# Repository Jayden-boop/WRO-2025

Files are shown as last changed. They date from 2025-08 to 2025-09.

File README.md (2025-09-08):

## Content

* `t-photos` contains 2 photos of the team as well as a personal photo of each member.
* `v-photos` contains 6 photos of the vehicle (from every side, from top and bottom)
* `video` contains the video.md file with the link to a video where a driving demonstration exists
* `schemes` contains one or several schematic diagrams in the form of JPEG, PNG, or PDF of the electromechanical components illustrating all the elements (electronic components and motors) used in the vehicle and how they connect to each other.
* `src` contains the code of control software for all components that were programmed to participate in the competition
* `models` is for the files for models used by 3D printers, laser cutting machines, and CNC machines to produce the vehicle elements. If there is nothing to add to this location, the directory can be removed.
* `other` is for other files, which can be used to understand how to prepare the vehicle for the competition. It may include documentation on how to connect to an SBC/SBM and upload files there, datasets, hardware specifications, communication protocols descriptions etc. If there is nothing to add to this location, the directory can be removed.

Table of Contents
=====

- [The Team](#the-team)
  
  - [Team Photos](#team-photo)
  - [Jayden](#jayden)
  - [Arham](#arham)
  - [Trevor](#trevor)

- [JAT | WRO Documentation](#jat-wro-documentation)
  
  - [Task](#task)
  - [Challenge Descriptions](#challenge-descriptions)
    - [1. Open Challenge](#1-open-challenge)
    - [2. Obstacle Challenge](#2-obstacle-challenge)

- [Our Robot](#our-robot)
  
  - [Video Demonstrations](#video-demonstrations)

- [Engineering Design & Strategy](#engineering-design--strategy)
  
  - [Mobility Management](#mobility-management)
    - [Motor Selection and Implementation](#motor-selection-and-implementation)
    - [Wheels and Drivetrain Rationale](#wheels-and-drivetrain-rationale)
  - [Power and Sense Management](#power-and-sense-management)
    - [Power Source and Distribution](#power-source-and-distribution)
    - [Wiring Diagram](#wiring-diagram)
    - [Sensor Selection and Rationale](#sensor-selection-and-rationale)

  - [Custom Chassis Parts](#custom-chassis-parts)
  - [Mechanical Components](#mechanical-components)

- [Cost Report](#cost-report)

- [Measurements](#measurements)

- [Assembly Guide](#assembly-guide)
  
  - [Overview](#overview)
  - [Required Tools](#required-tools)
  - [Required Components](#required-components)
  - [Assembly Steps](#assembly-steps)
    - [Step 1: Chassis Foundation Assembly](#step-1-chassis-foundation-assembly)
    - [Step 2: Platform and Electronics Mounting](#step-2-platform-and-electronics-mounting)
    - [Step 3: Sensor Integration](#step-3-sensor-integration)
    - [Step 4: Drive System Integration](#step-4-drive-system-integration)
    - [Step 5: Custom Steering System Assembly](#step-5-custom-steering-system-assembly)
    - [Step 6: Wheel and Tire Installation](#step-6-wheel-and-tire-installation)
    - [Step 7: System Wiring and Connections](#step-7-system-wiring-and-connections)
    - [Step 8: Final Assembly and Testing](#step-8-final-assembly-and-testing)

- [Obstacle Avoidance](#obstacle-avoidance)
  
  - [1. Pillar Detection](#1-pillar-detection)
  - [2. Pillar Filtering and Prioritization](#2-pillar-filtering-and-prioritization)
  - [3. Steering and Control](#3-steering-and-control)
  - [4. Emergency Collision Handling](#4-emergency-collision-handling)
  - [5. Edge Case Handling](#5-edge-case-handling)
  - [6. Turn Handling, Line Detection, and Lap Counting](#6-turn-handling-line-detection-and-lap-counting)
  - [7. Exiting the Parking Lot](#7-exiting-the-parking-lot)
  - [8. Parking Sequence](#8-parking-sequence)

# The Team

## Team Photo

<table align="center">
  <tr>
    <td align="center" style="border: 2px solid #ccc; padding: 10px;">
      Normal Team Photo<br>
      <strong><em>Left: Jayden, Middle: Arham, Right: Trevor</em></strong>
    </td>
  </tr>
</table>

---

### Jayden

<p align="center">
  
</p>

> **Jayden Li** is a Grade 11 Student at Anderson CVI who loves programming, math, and robotics. In his free time, he plays and watches basketball. 

---

### Arham

<p align="center">
  
</p>

> **Syed Arham Wasti** is a Grade 11 Student at Anderson CVI who takes an interest in computer science and machine learning. His ambition drives him to use his skills to address issues he deeply cares about.

---

### Trevor

<p align="center">
  
</p>

> **Trevor Mcaskin** is a Grade 11 Student at Anderson who loves problem-solving. He enjoys working hands-on with robotics and mechanical systems. One of his hobbies is playing video games.

# JAT WRO Documentation

## Task

The WRO 2025 Future Engineers Self-Driving Cars Challenge tasks teams with designing an autonomous vehicle to complete dynamic racetrack laps and perform parallel parking, adapting to randomized layouts and traffic signs. Teams must also document their engineering process in a public GitHub repository, showcasing innovation, adaptability, and technical problem-solving.

### Challenge Descriptions:

#### 1\. Open Challenge

In this challenge, the vehicle must autonomously complete three laps on a racetrack whose layout randomizes each round. The run must be completed within the 3-minute time limit; otherwise, the attempt is terminated.

**Key Elements:**

-  The track may feature randomized corridor widths (narrow or wide sections) and varying starting positions.

- The track configuration (e.g., wall placements, starting zones) is determined by a randomization process before each round.

-  The navigation algorithms of the vehicle are critical, having to adapt in real time to an unseen wall and course arrangement without human intervention.

**Performance Goal:**
The goal is to maximize the consistency and speed of laps under unknown track conditions.

#### 2\. Obstacle Challenge

In this challenge, the vehicle must complete three complete laps on a track with randomly placed traffic signs and then perform a parallel parking maneuver in a designated area. If the vehicle collides with a traffic sign and knocks it out of the designated zone, the run is considered unsuccessful.

**Key Elements:**

- Red and green pillars indicate required driving lanes (red = keep right, green = keep left). The vehicle must obey these rules without displacing the signs.
- After completing laps, the vehicle must park within a narrow, variable-sized parking space. Starting inside the parking lot and achieving parallel alignment earns bonus points.

**Randomization factors:**

- Traffic sign positions
- Parking lot placement
- Driving direction (clockwise/counterclockwise)

**Performance Goal:**
Complete the 3 laps without faults and complete a precise parallel parking maneuver whilst adapting to randomized factors.

# 

Our Robot
=====

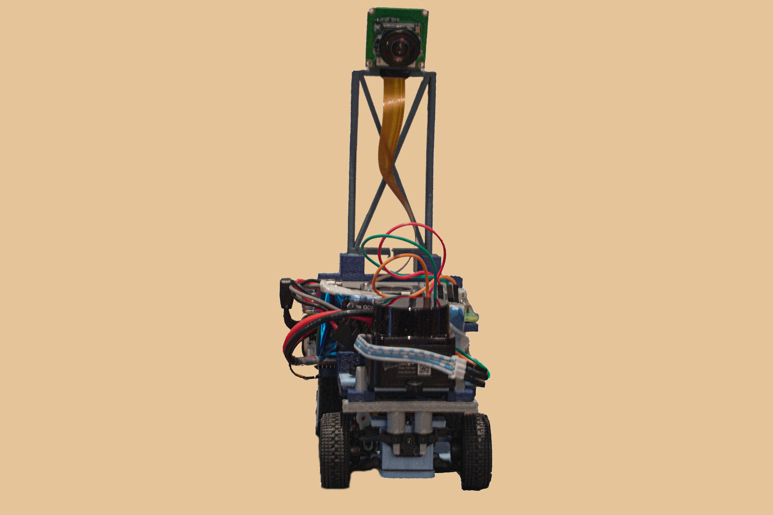
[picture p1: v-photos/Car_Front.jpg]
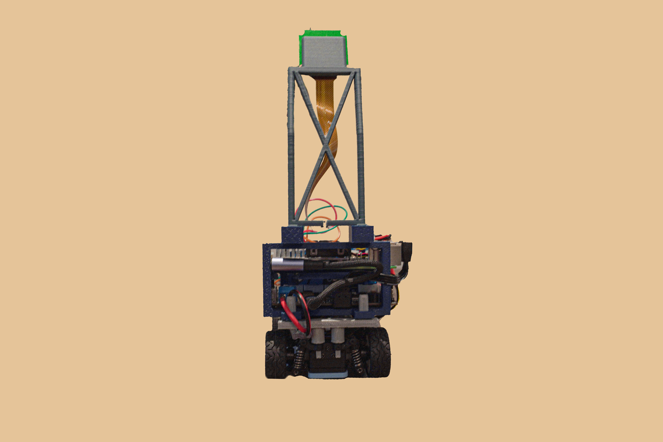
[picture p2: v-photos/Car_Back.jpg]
|  |  |
|:---:|:---:|
| *Front* | *Back* |
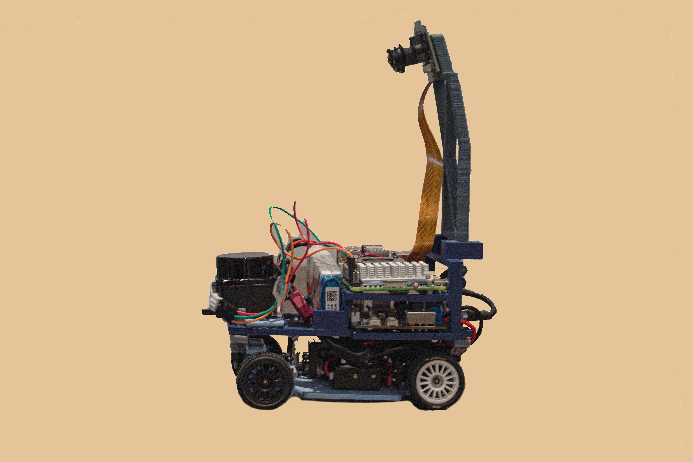
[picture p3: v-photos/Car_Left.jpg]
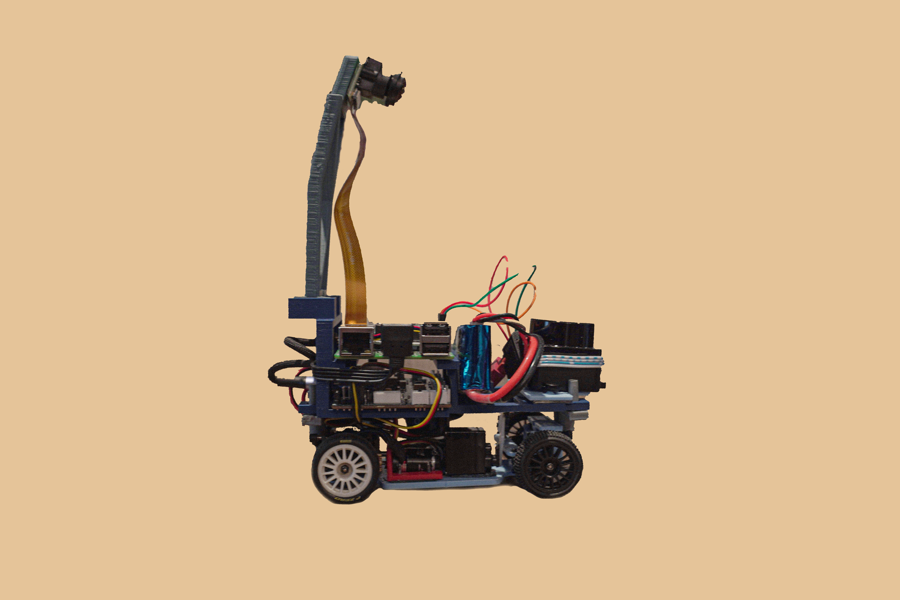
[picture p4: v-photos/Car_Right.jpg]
|   |   |
| *Left* | *Right* |
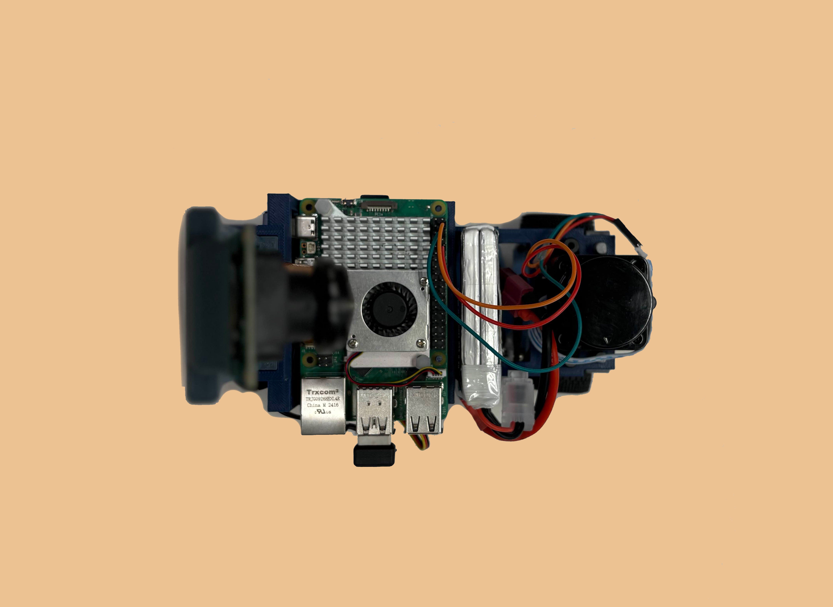
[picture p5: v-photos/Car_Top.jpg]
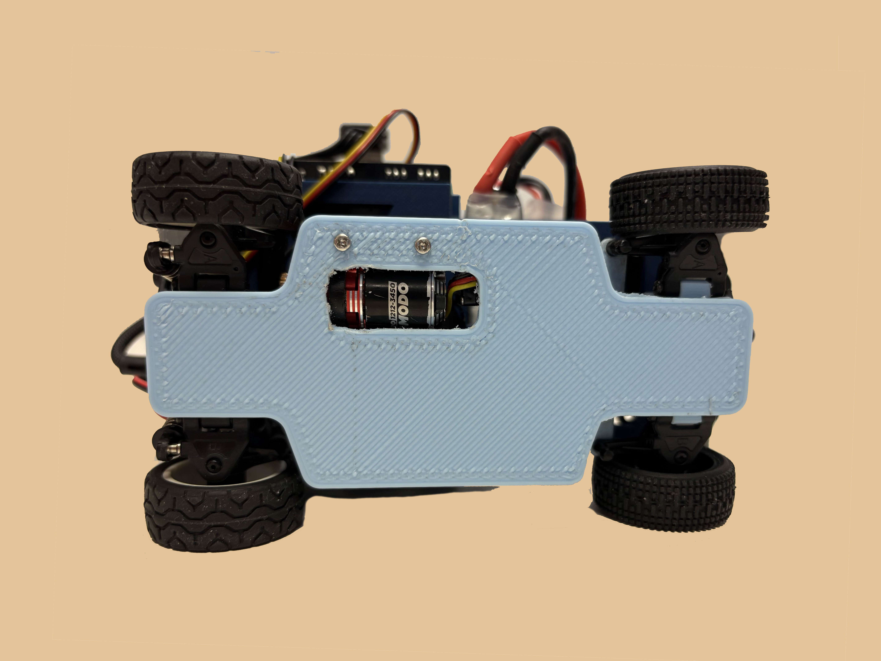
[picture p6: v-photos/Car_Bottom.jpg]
|  |  |
| *Top* | *Bottom* |

<p align="center">
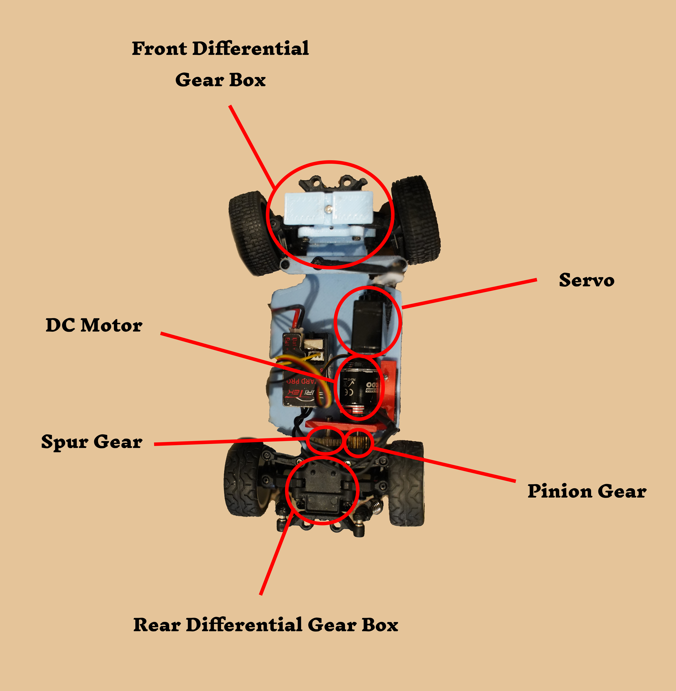
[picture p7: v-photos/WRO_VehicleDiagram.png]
 
   </p>
<br>

<br>

## Video Demonstrations

<table>
  <tr>
    <th>Open Challenge</th>
    <th>Obstacle Challenge</th>
  </tr>
  <tr>
    <td align="center">
      <a href="https://www.youtube.com/watch?v=GPGMuM1HHgo" target="_blank">
        Open Challenge
      </a>
    </td>
    <td align="center">
      <a href="https://www.youtube.com/watch?v=hhrCKOZkAMQ" target="_blank">
        Obstacle Challenge
      </a>
    </td>
  </tr>
</table>

<div align="center"><small><em>Click the images for the video demonstrations!</em></small></div>

# Engineering Design & Strategy

This section outlines the core engineering principles and strategic decisions that guided the development of our autonomous vehicle. We have broken down our design process into the key categories evaluated in the competition: Mobility, Power & Sensing, and Obstacle Management.

## Mobility Management

Effective mobility is central to navigating the course quickly and accurately. Our design focuses on a responsive drivetrain with precise steering control.

### Motor Selection and Implementation

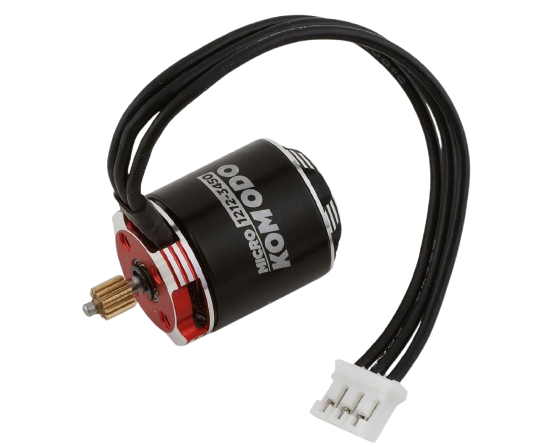
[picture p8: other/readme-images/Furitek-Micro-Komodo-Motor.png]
Furitek Micro Komodo Motor
<table width="800px"> <tr> <td width="400px" style="text-align: left; vertical-align: top;">  </td> <td width="400px" style="text-align: left; vertical-align: top;"> <h3>Furitek Micro Komodo Motor</h3> <ul> <li><b>KV:</b> 3450 RPM/Volt</li> <li><b>Power:</b> 120W</li> <li><b>Battery:</b> 2–3S LiPo</li> <li><b>Type:</b> Brushless</li> <li><b>Weight:</b> 17.5 g</li> </ul> </td> </tr> </table>

The Furitek Micro Komodo was selected for its exceptional power-to-weight ratio and precise speed control. As a brushless motor, it offers higher efficiency, a longer lifespan, and superior performance compared to brushed alternatives. Its ability to operate smoothly at both high and very low speeds is a significant advantage, providing the raw acceleration needed for fast laps and the delicate, slow-speed control required for the parallel parking maneuver. 

A 3D motor mount secures the motor to the chassis, allowing for full transfer of energy to the rear gearbox. It is screwed into the motor and chassis using M3 screws. 

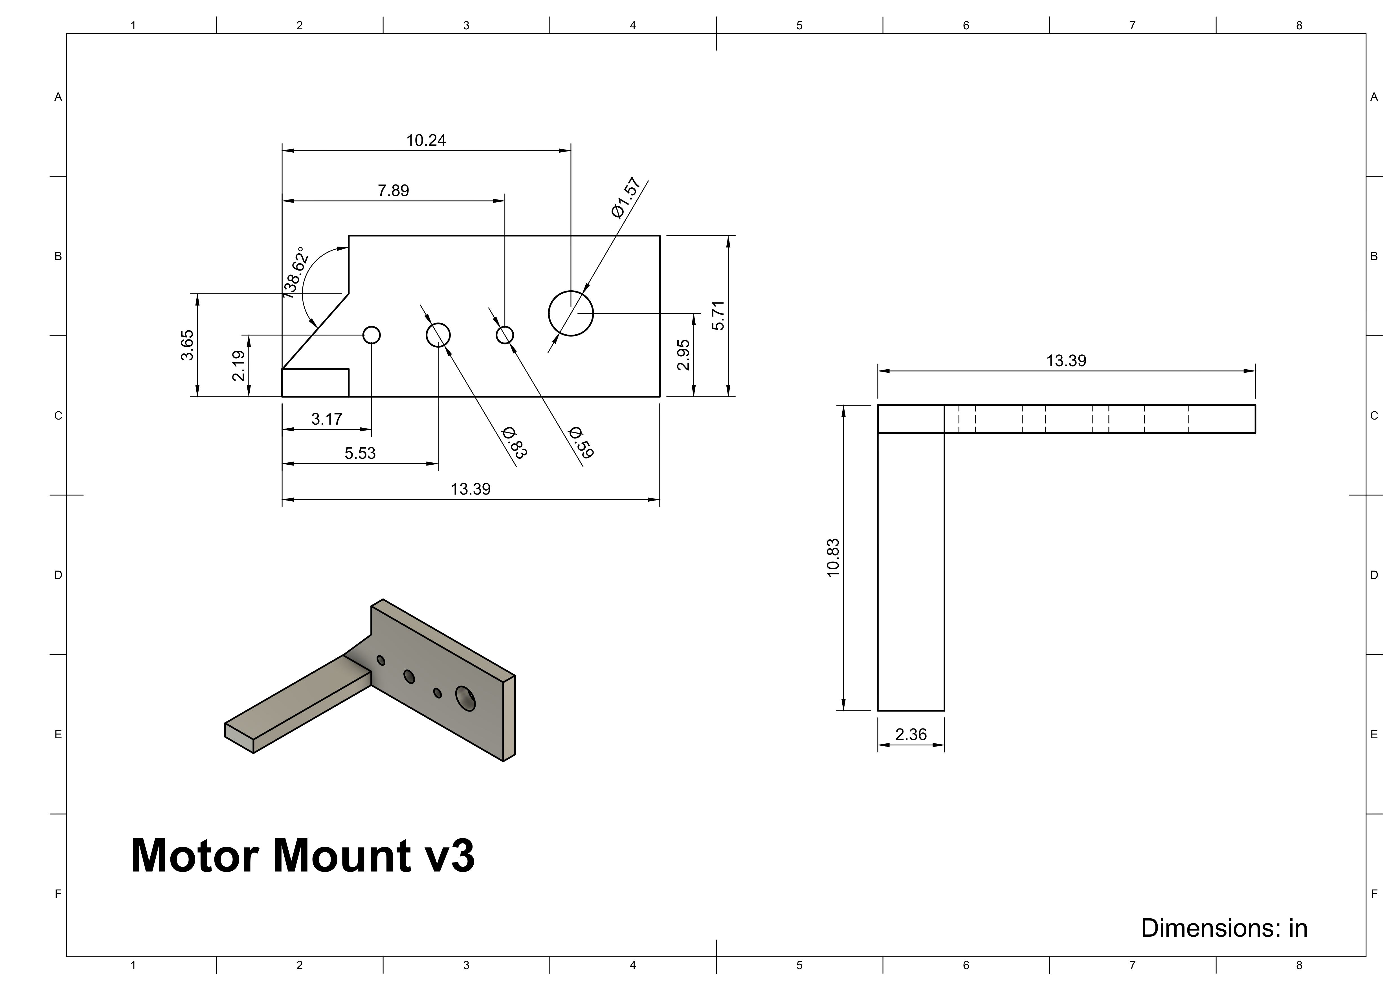
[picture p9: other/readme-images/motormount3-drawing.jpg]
Motor Mount Drawing


<table width="800px">
  <tr>
    <td width="400px" style="text-align: left; vertical-align: top;">
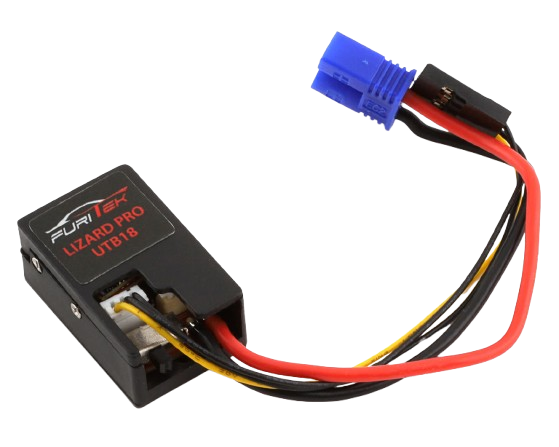
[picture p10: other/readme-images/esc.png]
Furitek Lizard Pro ESC
      
    </td>
    <td width="400px" style="text-align: left; vertical-align: top;">
      <h3>Furitek Lizard Pro ESC</h3>
      <ul>
        <li><b>Current:</b> 30A Constant / 50A Burst</li>
        <li><b>Battery:</b> 2–3S LiPo</li>
        <li><b>BEC:</b> 5V or 6.5V @ 2.5A</li>
        <li><b>Type:</b> Brushed/Brushless</li>
        <li><b>Weight:</b> 3.7 g</li>
      </ul>
    </td>
  </tr>
</table>

The ESC was selected for its light weight and small frame. It allows for simple calibration using the FURITEK app and supports the BLDC motor we selected. 

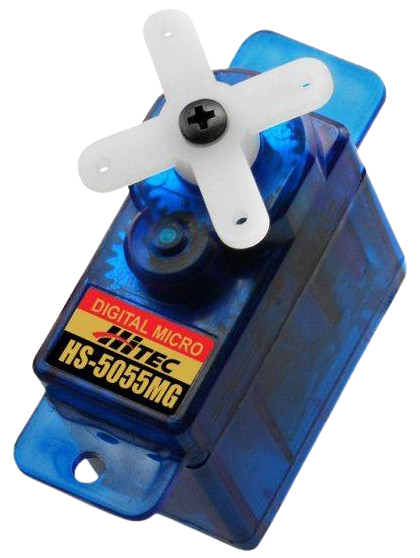
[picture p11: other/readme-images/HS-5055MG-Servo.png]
HS-5055MG Servo
<table width="800px"> <tr> <td width="400px" style="text-align: left; vertical-align: top;">  </td> <td width="400px" style="text-align: left; vertical-align: top; padding: 0;"> <h3>HS-5055MG Servo</h3> <ul> <li><b>Torque (6.0V):</b> 1.4 kg/cm</li> <li><b>Speed (6.0V):</b> 0.14 sec/60°</li> <li><b>Gears:</b> Metal</li> <li><b>Type:</b> Digital</li> <li><b>Weight:</b> 9.5 g</li> </ul> </td> </tr> </table>

Accurate path following is managed by a PID controller, which requires a steering servo capable of making small, precise, and rapid adjustments. The HS-5055MG was chosen for its digital precision and metal gear construction, providing the durability and responsiveness needed to translate the PID controller's outputs into exact steering angles. This ensures the vehicle can hold its line with minimal error.

### Wheels and Drivetrain Rationale

We use GT24 Carisma Wheels and Tires for their traction characteristics, ensuring consistent grip and power delivery. Other 1/24 scale RC car wheels and tires can be substituted.

## Power and Sense Management

A reliable power system and an accurate sensor suite are the foundation of any autonomous system. Our strategy was to choose components that provide clean power and rich, low-latency data to our control system.

### Power Source and Distribution

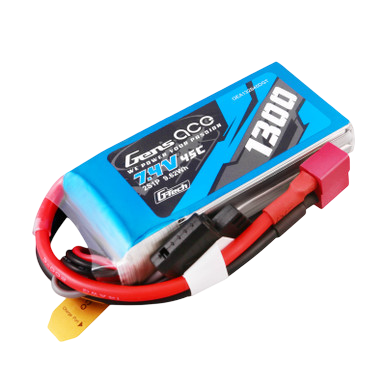
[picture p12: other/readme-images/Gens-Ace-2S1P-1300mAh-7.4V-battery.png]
Gens Ace 2S1P 1300mAh 7.4V battery
<table width="800px"> <tr> <td width="400px" style="text-align: left; vertical-align: top;">  </td> <td width="400px" style="text-align: left; vertical-align: top;"> <h3>Gens Ace 2S LiPo Battery</h3> <ul> <li><b>Capacity:</b> 1300mAh</li> <li><b>Voltage:</b> 7.4V (2S)</li> <li><b>Discharge Rate:</b> 45C</li> <li><b>Weight:</b> 90 g</li> </ul> </td> </tr> </table>

The Gens Ace 1300mAh LiPo was selected for its optimal balance of capacity, weight, and size. On a full charge, this battery provides approximately 45 minutes of continuous runtime, which is more than sufficient to complete all competition rounds and practice runs without needing a battery swap or experiencing performance degradation.

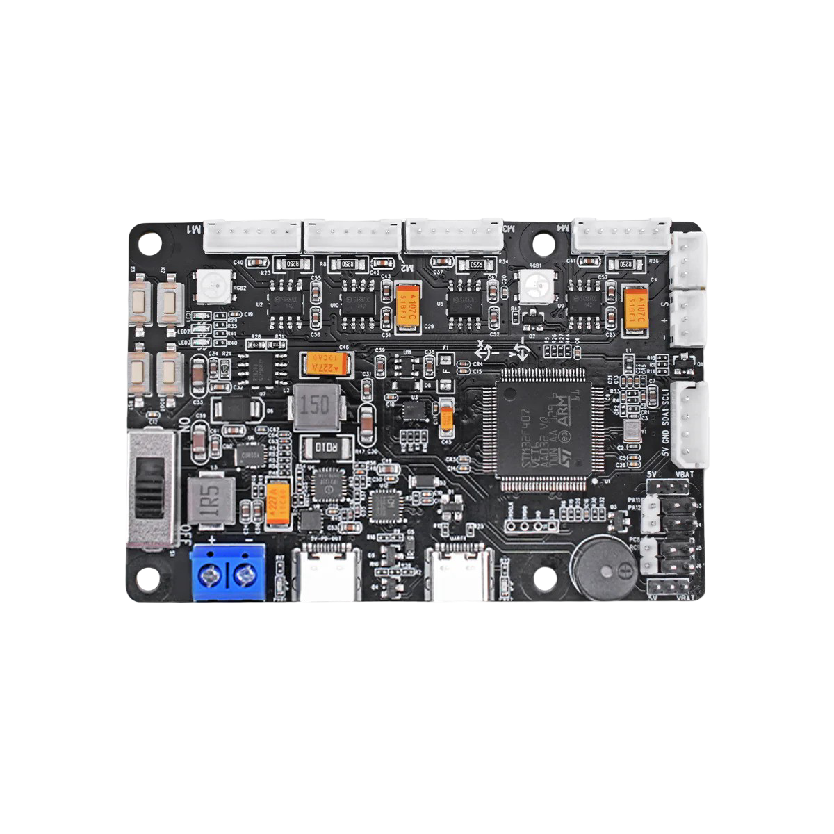
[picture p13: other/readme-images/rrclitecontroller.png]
Hiwonder Raspberry Pi 5 Expansion Board
<table width="800px"> <tr> <td width="400px" style="text-align: left; vertical-align: top;"> <h3>Hiwonder Raspberry Pi 5 Expansion Board</h3> <ul> <li>Centralized Power Distribution</li> <li>Organized PWM Outputs</li> <li>Regulated Voltage for Sensors</li> <li>Direct Pi 5 Connectivity</li> </ul> </td> <td width="400px" style="text-align: left; vertical-align: top;">  </td> </tr> </table>

To eliminate the reliability issues of breadboards and loose wiring, we integrated the Hiwonder Expansion Board. It serves as a centralized hub for power management and signal distribution, providing stable, regulated power to the Pi, sensors, and servos. This simplifies the wiring harness, reduces potential failure points, and ensures consistent performance from all electronic components.

### Wiring Diagram

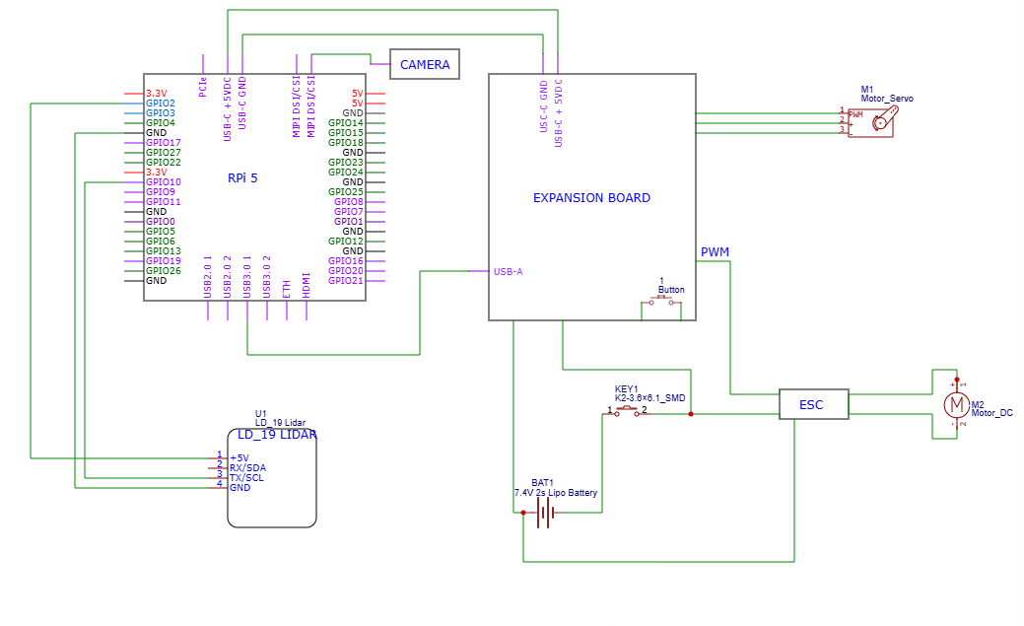
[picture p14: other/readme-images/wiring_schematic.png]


### Sensor Selection and Rationale

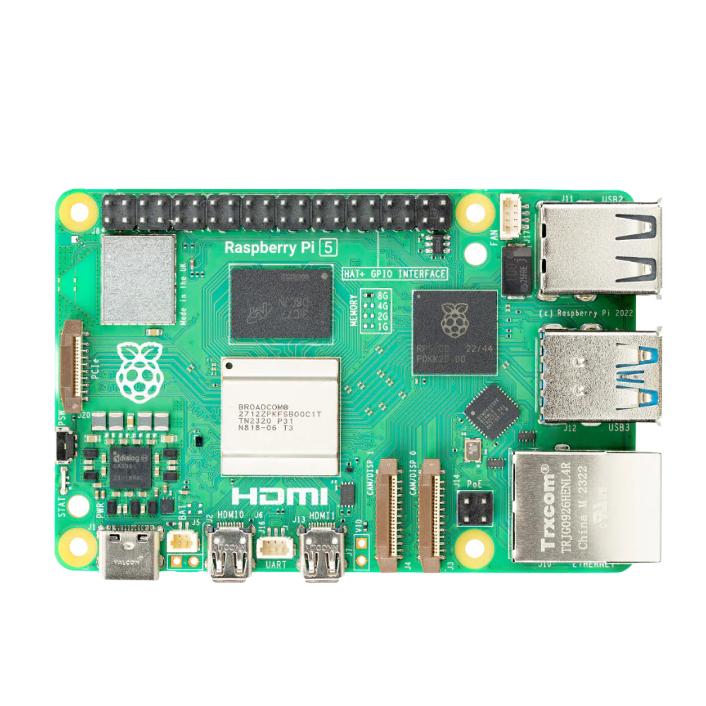
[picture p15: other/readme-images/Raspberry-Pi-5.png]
Raspberry Pi 5
<table width="800px"> <tr> <td width="400px" style="text-align: left; vertical-align: top;">  </td> <td width="400px" style="text-align: left; vertical-align: top;"> <h3>Raspberry Pi 5</h3> <ul> <li><b>CPU:</b> Quad-core 64-bit Arm Cortex-A76 @ 2.4GHz</li> <li><b>RAM:</b> 8GB LPDDR4X</li> <li><b>Connectivity:</b> Wi-Fi, Bluetooth 5.0, Gigabit Ethernet</li> <li><b>I/O:</b> 40-pin GPIO, 2x MIPI DSI/CSI</li> </ul> </td> </tr> </table>

The Raspberry Pi 5 serves as the central processing unit, chosen for its powerful quad-core processor that can simultaneously handle real-time data streams from the camera and LiDAR without performance bottlenecks. The mature Python ecosystem and extensive GPIO interface were ideal for rapid algorithm development and direct control over all hardware.

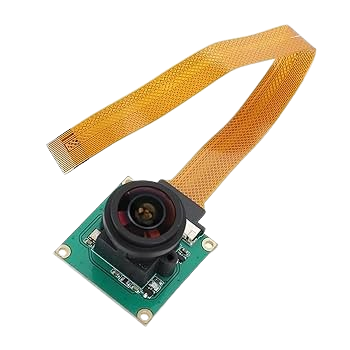
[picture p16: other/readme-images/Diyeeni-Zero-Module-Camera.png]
Pi Camera Module
<table width="800px"> <tr> <td width="400px" style="text-align: left; vertical-align: top;">  </td> <td width="400px" style="text-align: left; vertical-align: top;"> <h3>Pi Camera Module</h3> <ul> <li><b>Resolution:</b> 5 Megapixels</li> <li><b>Video:</b> 1080p HD</li> <li><b>Interface:</b> Direct CSI</li> <li><b>Features:</b> Color Sensing</li> </ul> </td> </tr> </table>

The Pi Camera is our primary sensor for the Obstacle Challenge. Its direct CSI interface provides a low-latency video feed essential for high-speed decision-making. We rely entirely on its color-sensing capabilities and OpenCV-based contour detection to accurately identify the pillars and boundary walls. The 175° wide angle lens, combined with a high mounting position on the chassis, allows the camera to have an extremely large field of view throughout the challenge.

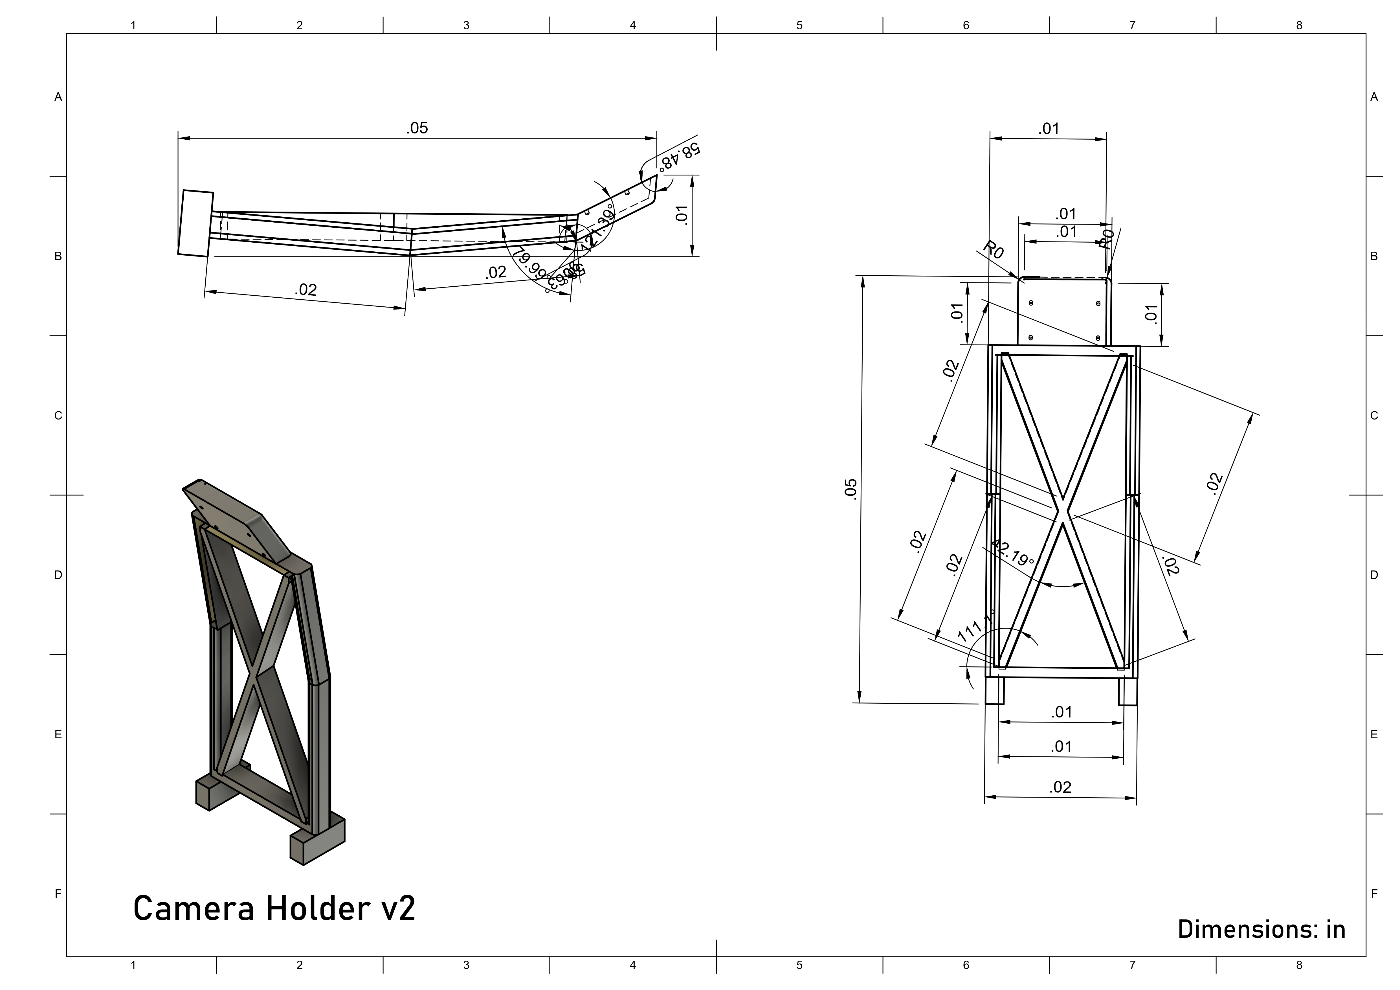
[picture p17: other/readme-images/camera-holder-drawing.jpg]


The camera is mounted to a custom-built holder. The holder is fixed to the back of the chassis. This allows for the maximum reaction window for obstacles. 

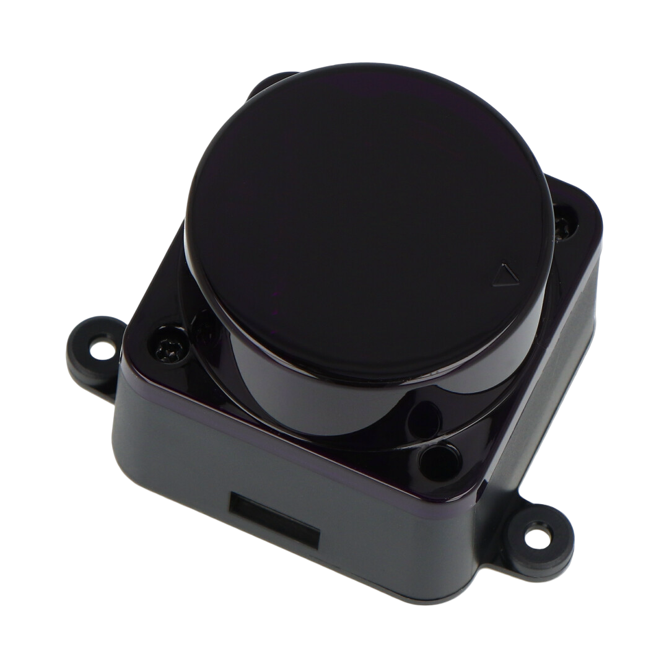
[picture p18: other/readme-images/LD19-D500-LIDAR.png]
LD19 D500 LIDAR
<table width="800px"> <tr> <td width="400px" style="text-align: left; vertical-align: top;"> <h3>LD19 D500 LIDAR</h3> <ul> <li><b>Range:</b> 0.02 - 12m</li> <li><b>Scan Rate:</b> 5-15 Hz</li> <li><b>Angular Resolution:</b> 0.5°</li> <li><b>Interface:</b> UART</li> </ul> </td> <td width="400px" style="text-align: left; vertical-align: top;">  </td> </tr> </table>
For navigation tasks where precision distance measurement is needed, we use the LD19 LIDAR. It is the sole sensor for the parallel parking maneuver. Once the parking sequence is initiated, color data is no longer needed, and the LIDAR's high-accuracy spatial data allows us to precisely detect the parking space and execute the multiple turns required to park.

A 3d printed lidar holder ensures that the lidar is completely flat and level to the ground. 

## Custom Chassis Parts

### Custom 3D Printed Platform

The main chassis and structural components are 3D printed in PLA plastic. PLA was selected for its excellent dimensional stability, ease of printing complex geometries, and sufficient strength for the application.  The material allows for rapid prototyping iterations during development while providing the precision needed for proper component mounting and alignment.

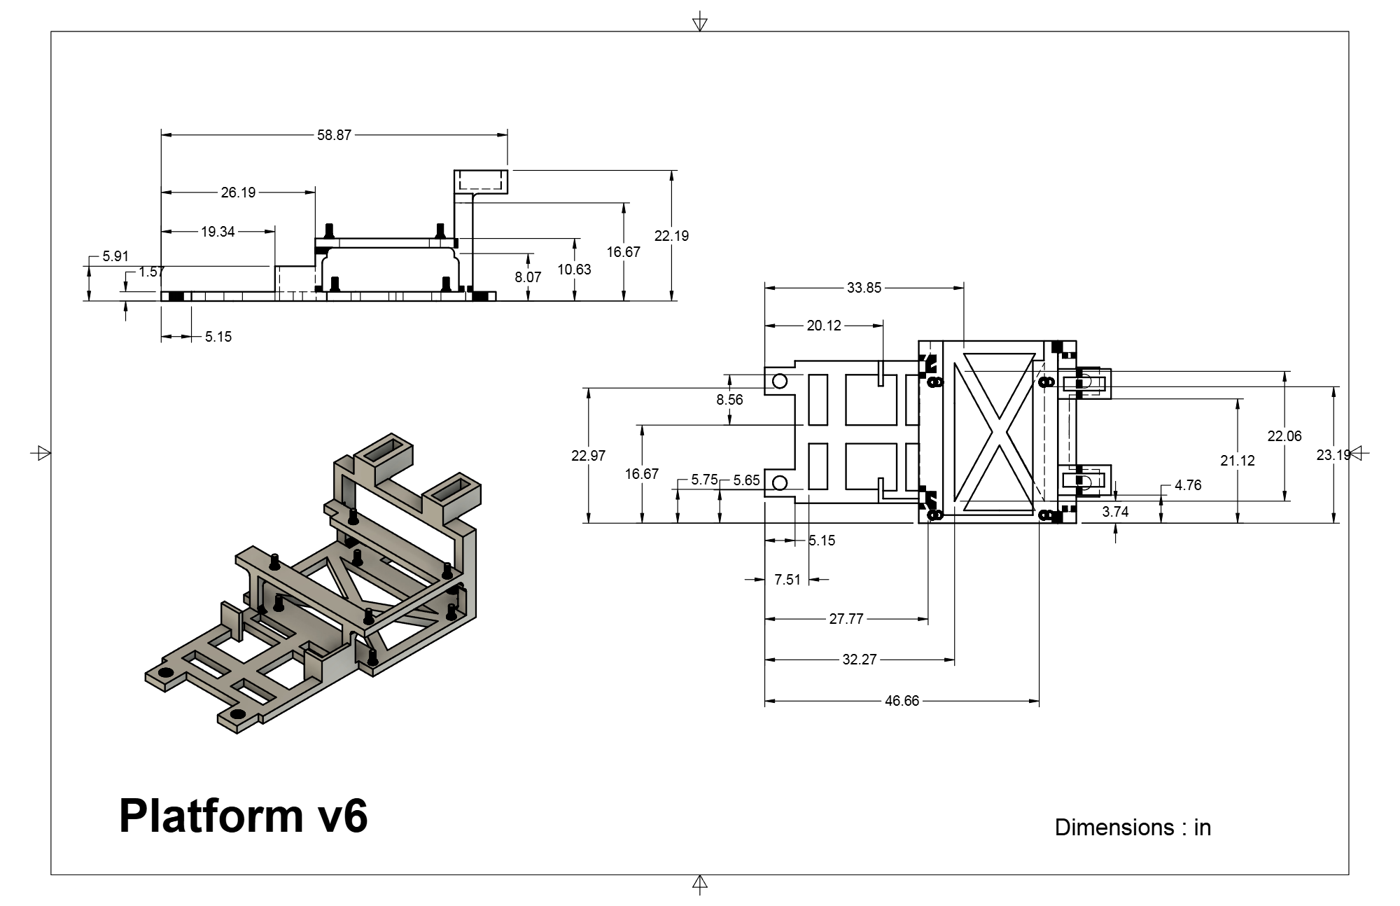
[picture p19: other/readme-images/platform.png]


The lightweight chassis platform provides housing space for the lidar, battery, Raspberry Pi, expansion board, and camera holder. It is directly attached to the front and back gearboxes through two 3d-printed supports that ensure the platform is secure and level to the ground. 

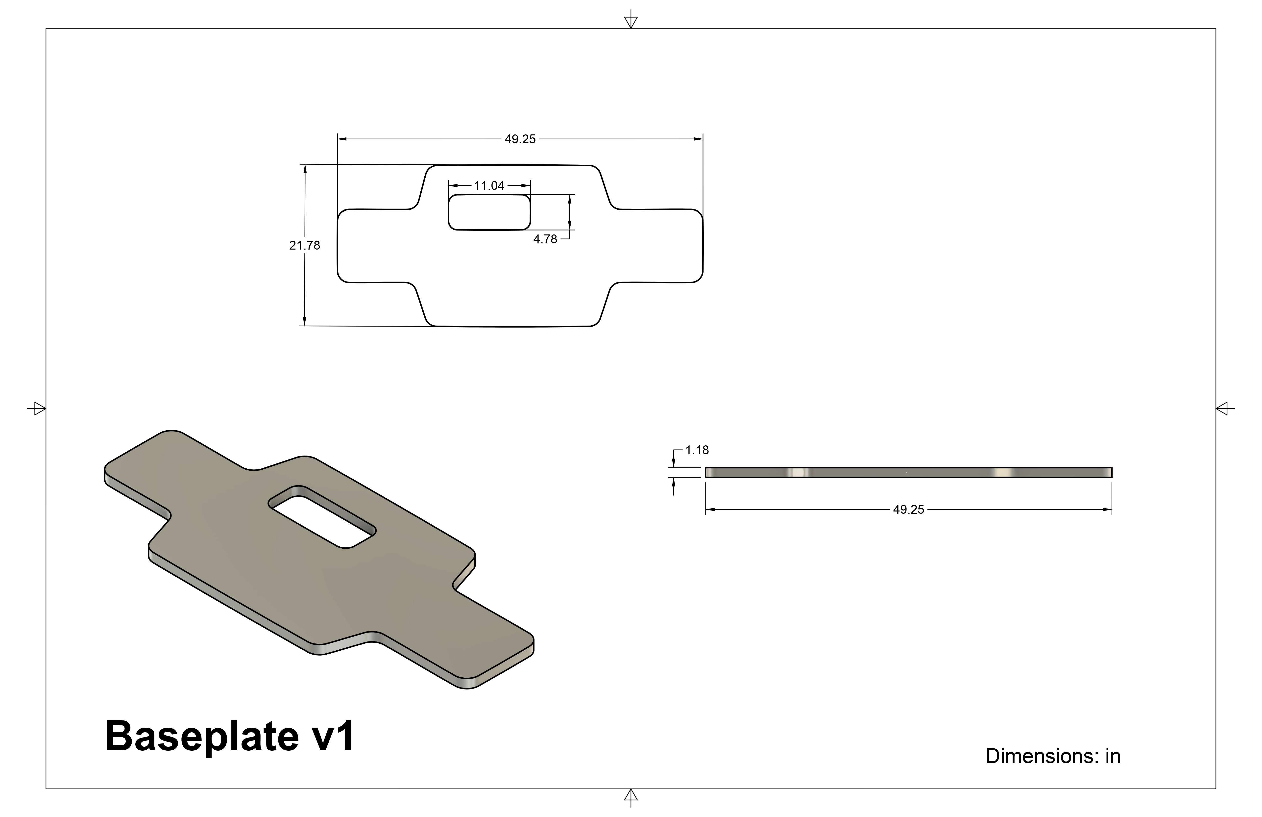
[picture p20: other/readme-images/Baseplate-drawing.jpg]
Baseplate Drawing


A thin and lightweight baseplate houses the DC motor and its mount, the ESC, the servo,   the rear gearbox, and the front steering block. The simplistic design allows for easy positioning changes using double-sided tape. 

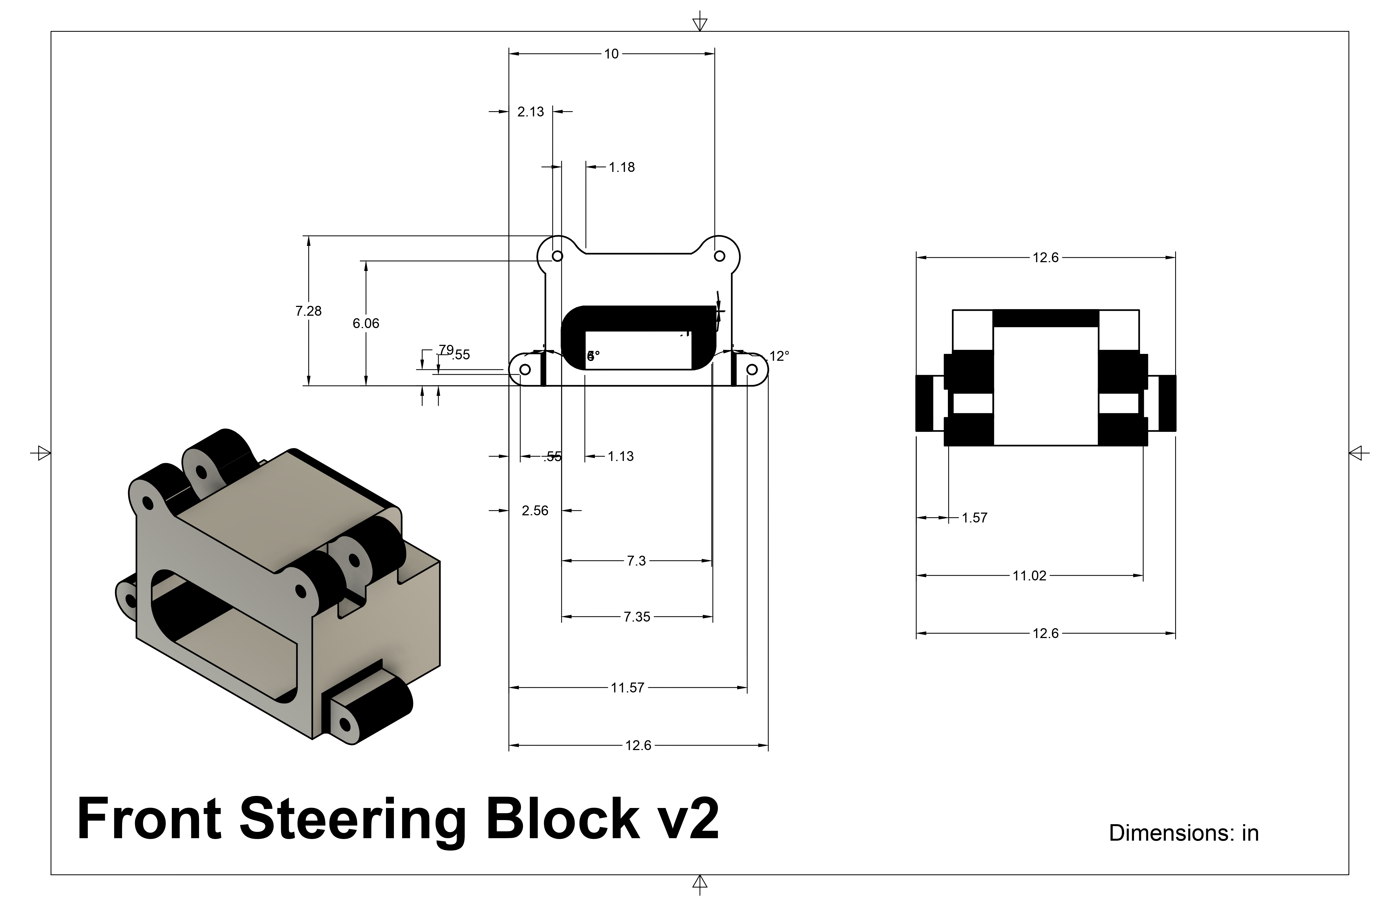
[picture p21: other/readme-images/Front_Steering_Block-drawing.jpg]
Front_Steering Block


The custom-built front steering block allows for adequate clearance for the steering system while securing the front two wheels. 

## Mechanical Components

### K989 Drivetrain Components

The design adapted select components from the K989 platform, including the rear gearbox assembly and steering linkage ball joints. These parts provide proven reliability and appropriate gear ratios for the scale and performance requirements while maintaining cost effectiveness.

### Standard Metric Hardware

All mechanical connections use standard M3 screws and fasteners for reliability and easy maintenance. Double-sided mounting tape provides secure attachment for electronic components while allowing for adjustments during development.

### Ball Joint Steering Links

Precision ball joints from the K989 system ensure smooth steering operation with minimal backlash, critical for accurate autonomous navigation.

## Cost Report

| Component | Quantity | Unit Price (CAD) | Total Cost (CAD) | Link |
| --- | --- | --- | --- | --- |
| Raspberry Pi 5 (8GB) | 1 | $139.99 | $139.99 | [Link](https://www.canakit.com/raspberry-pi-5-16gb.html?cid=CAD&src=raspberrypi) |
| Pi 5 Expansion Board | 1 | $55.87 | $55.87 | [Link](https://www.hiwonder.com/products/expansion-board-for-raspberry-pi-5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) |
| HS-5055MG Servo | 1 | $34.91 | $34.91 | [Link](https://ca.robotshop.com/products/hs-5055mg-metal-gear-micro-servo-motor) |
| K989 1/28 WL Toys Chassis | 1 | $105.68 | $105.68 | [Link](https://www.amazon.ca/Baugger-Drift-Speed-Sport-Racing/dp/B09YM6YGZF) |
| Furitek Micro Komodo Motor and Furitek Lizard Pro Esc (sold together) | 1 | $112.71 | $112.71 | [Link](https://furitek.com/products/furitek-micro-komodo-brushless-motor) |
| LDRobot D500 LiDAR Kit | 1 | $99.60 | $99.60 | [Link](https://www.amazon.ca/LDROBOT-Outdoor-Navigation-Scanning-Support/dp/B0DDKXQ23R) |
| Snap-in Boat Rocker Switch Toggle Power | 1 | $1.62 | $1.62 | [Link](https://www.aliexpress.com/item/1005008317476851.html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) |
| Gens Ace 2S LiPo Battery (2S LiPo 7.4V ~2000mAh) | 2 | $80.35 | $160.70 | [Link](https://www.greathobbies.com/productinfo/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) |
| Diyeeni Zero Module Camera (5MB, 1080p HD) | 1 | $46.85 | $46.85 | [Link](https://www.amazon.ca/Raspberry-Camera-Module-OV5647-Sensor/dp/B0D324RKRZ) |
| GT24 M-Sport 2022 Hybrid Rally Wheels & Tires | 1 | $22.00 | $22.00 | [Link](https://carisma-shop.com/products/gt24-m-sport-2022-puma-hybrid-rally1-wheels-tires-set) |
| USB to USBC adapter | 1 | $4.99 | $4.99 | [Link](https://www.amazon.ca/Charging-Compatible-Samsung-OnePlus-Stations/dp/B09XXNDP6F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) |
| USBC to USBC wire | 1 | $5.64 | $5.64 | [Link](https://www.amazon.ca/Earphones-Headphones-Smartphones-PowerBanks-Portable/dp/B08X365B5Y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) |

## Measurements

| Part | Measurement | Rule Comp |
| --- | --- | --- |
| Vehicle Length | 18.2cm | 30cm |
| Vehicle Width  | 10.0cm | 20cm |
| Vehicle Height | 22.4cm | 30cm |
| Weight | 397g | 1.5kg |

We opted to create a chassis based on a 1/28 sized car. This allows us to maneuver between obstacles and parallel park with ease. Our low weight contributes to smooth and consistent movement. 

# Assembly Guide

## Overview

This guide provides comprehensive step-by-step instructions for assembling our fully custom-designed WRO Future Engineers autonomous vehicle. The robot features a completely custom 3D-printed chassis system with integrated drive components and precision steering mechanism.

## Required Tools

- Phillips head screwdrivers (various sizes)
- Soldering iron and solder
- Wire strippers
- Digital calipers (for precise positioning)

## Required Components

### Custom 3D-Printed Chassis System

- Main chassis baseplate (PLA, 20% infill, 0.2mm layer height)
- Custom front gearbox housing
- Main electronics platform with integrated mounting pins
- Camera mount tower (approximately 80mm height)
- Custom front wheel rims
- Custom platform holders and mounting adapters
- Custom track rod with ball joint connections
- Custom Lidar holder
- Custom wheel clearance support

### Drive System Components

- Rear gearbox assembly (K989 reference components)
- Custom front gearbox assembly
- FURITEK LIZARD Pro 30A/50A Brushed/Brushless ESC
- Drive motor with Furitek Micro Komodo controller
- Steering servo motor
- K989 steering rod components

### Electronics & Control

- Raspberry Pi 5
- Custom expansion board
- Pi Camera module with CSI ribbon cable
- LD19 D500 LIDAR sensor
- LiPo battery pack (rectangular form factor)

### Wheels and Tires

- Custom 3D-printed front rims with K989 tires (1/28 scale stretched fit)
- Rear wheels with GT24 Carisma tires (or any compatible 1/24 scale tires)

### Hardware & Fasteners

- M3 screws (various lengths for gearbox mounting)
- Double-sided mounting tape (high strength)
- K989 ball joints for steering linkage
- Axle nuts for wheel attachment
- Male-to-female jumper wires (3-wire set for LIDAR)

## Assembly Steps

### Step 1: Chassis Foundation Assembly

1. **Print 3D parts**
   - Retrieve STL files found in the `models` folder
   - Print parts on any accessible supported 3D printer
2. **Prepare the main chassis baseplate**
   - Ensure all mounting points are clear of support material
   - Test fit all major components before permanent installation
3. **Install rear gearbox assembly**
   - Position K989 rear gearbox in chassis mounting location
   - Secure using double-sided tape for primary attachment
   - Screw in the K989 body mounting holes into the front gearbox
   - Install custom 3D-printed platform holders onto K989 body mounting points 
4. **Install custom front gearbox housing**
   - Mount the front gearbox assembly to the chassis front section
   - Ensure proper alignment with steering geometry
   - Secure with double-sided tape
   - Screw in the K989 wheel connector parts from the stock front gearbox
   - Screw in the custom wheel holder piece to ensure optimal clearance between the ground and the chassis

### Step 2: Platform and Electronics Mounting

1. **Install main electronics platform**
   - Align platform with front and rear mounting points
   - Insert the platform into the custom holders through the designed holes
   - Verify the platform is level and secure
2. **Mount Raspberry Pi 5 and expansion board**
   - Align the Raspberry Pi with the integrated mounting pins on the platform
   - Press Pi onto pins through standard mounting holes
   - Install the expansion board using the same pin mounting method
   - Ensure both boards are seated securely
   - Connect two USBC ports of the boards
   - Connect one USBC port of the expansion board with a USB-A port of the Raspberry Pi
3. **Install LiPo battery**
   - Place rectangular LiPo battery on its side (long edge down)
   - Position between platform sidewalls for a friction fit
   - Verify battery is held securely by platform walls

### Step 3: Sensor Integration

1. **Mount LD19 D500 LIDAR**
   - Position the LIDAR on the custom holder piece
   - Attach the holder piece to the platform using double-sided tape
   - Ensure LIDAR is parallel to the ground plane
   - Verify rotation clearance and mounting stability
2. **Install camera mount tower**
   - Position the camera mount at the rear of the platform
   - Insert rectangular mounting beams into platform holes for a friction fit
   - Verify tower is vertical and stable
   - Test camera field of view clearance
3. **Mount Pi Camera**
   - Install Pi Camera in fixed mount position on tower using double-sided tape
   - Connect the CSI ribbon cable to the Raspberry Pi
   - Route cable carefully to avoid interference with moving parts
   - Verify camera orientation and focus adjustment

### Step 4: Drive System Integration

1. **Install Furitek Micro Komodo and ESC**
   - Mount the Furitek Micro Komodo controller to the custom motor mount
   - Connect the drive motor to the controller
   - Install FURITEK LIZARD Pro ESC between the controller and the expansion board
   - Secure all components with an appropriate mounting method
2. **Connect drive system wiring**
   - Connect the ESC to the expansion board using the PWM signal pins
   - Ensure proper power distribution from the battery
   - Verify all electrical connections are secure
   - Use the FURITEK app to calibrate the motor

### Step 5: Custom Steering System Assembly

1. **Install steering servo**
   - Mount the steering servo in the designated chassis location using double-sided tape
   - Connect the servo to the expansion board using the PWM pins
   - Verify servo movement range and centering
2. **Assemble steering linkage**
   - Attach K989 steering rod to servo horn
   - Connect the custom track rod with ball joints to the steering rod
   - Install ball joint connections to front wheel assemblies
   - Verify Ackermann steering geometry implementation
   - Test steering range - track rod should contact the front gearbox at maximum turns
3. **Verify steering operation**
   - Check full steering range without binding
   - Ensure proper return to center position
   - Verify ball joint security and movement

### Step 6: Wheel and Tire Installation

1. **Install wheels**
   - Mount rear wheels to rear axles
   - Install GT24 Carisma tires or any compatible 1/24 scale tires
   - Secure with stock fasteners from Carisma GT24 or K989
   - Verify proper clearance and alignment

### Step 7: System Wiring and Connections

1. **LIDAR connections**
   - Connect 3-wire harness (VCC, GND, Data) using male-to-female jumpers
   - Connect GND to any GPIO ground pin
   - Connect VCC and data signal to the appropriate GPIO pins
   - Verify UART communication setup
2. **Power distribution**
   - Solder the rocker switch into the battery wire
   - Solder both the wires for the expansion board and esc according to the diagram
   - Screw in the wire to the expansion board
   - Use a voltmeter to validate correct wiring.

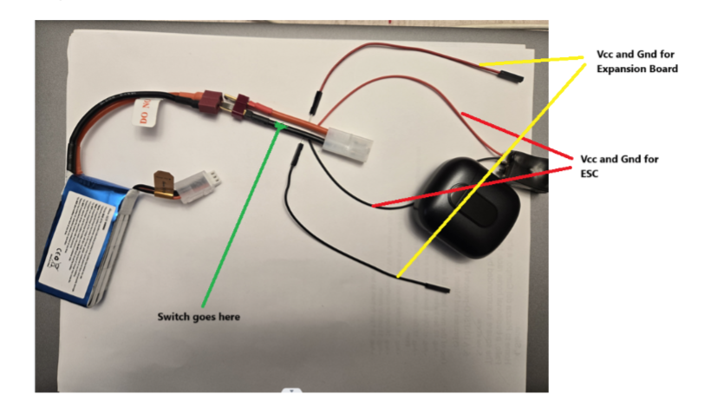
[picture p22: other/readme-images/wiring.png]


### Step 8: Final Assembly and Testing

1. **Mechanical verification**
   - Check all mounting points for security
   - Verify steering range and drive system operation
   - Ensure no mechanical binding or interference
2. **Electrical testing**
   - Power on the system and verify all components are initialized
   - Test LIDAR rotation and data output
   - Verify camera image capture
   - Test steering servo response
   - Verify drive motor operation through the ESC
3. **Software preperation**
   - Flash the custom Raspberry Pi 5 Bookworm OS onto a micro SSD, insert it into your Pi, and power on the device
   - Connect to the HW-{numbers & letters} access point that appears using the password hiwonder
   - Download RealVNC and connect to 192.168.149.1 to access the Pi remotely

# Obstacle Avoidance

This section explains the **pillar detection and obstacle avoidance algorithm** implemented for the obstacle and open challenge. It covers detection, filtering, steering control, emergency handling, edge cases, parking exit logic, and the parallel parking process.

---

## 1. Pillar Detection

### Color Thresholding

The camera frame is converted to HSV, and color thresholds are applied to isolate pillar colors. Red uses two hue ranges to handle hue wrap-around and lighting changes; green uses a single calibrated range. The thresholds are tuned to avoid false positives from track lines and printed textures.

```python
img_hsv = cv2.cvtColor(im, cv2.COLOR_BGR2HSV)

# Green mask (single continuous hue band)
img_thresh_green = cv2.inRange(img_hsv, LOWER_GREEN_THRESHOLD, UPPER_GREEN_THRESHOLD)

# Red mask (hue wraps near 0 / 180 — use two ranges and OR them)
img_thresh_red = cv2.bitwise_or(
    cv2.inRange(img_hsv, LOWER_RED_THRESHOLD1, UPPER_RED_THRESHOLD1),
    cv2.inRange(img_hsv, LOWER_RED_THRESHOLD2, UPPER_RED_THRESHOLD2)
)
```

On many cameras, red hues can be split across the 0/180 boundary in HSV. The two-range approach reduces missed red detections under variable illumination or white balance shifts.

### Contour Extraction & Preprocessing

Contours are found on the thresholded masks. To minimize noisy edges, the code uses `CHAIN_APPROX_NONE` while later smoothing contours.

```python
contours_red, _ = cv2.findContours(img_thresh_red, cv2.RETR_EXTERNAL, cv2.CHAIN_APPROX_NONE)
contours_green, _ = cv2.findContours(img_thresh_green, cv2.RETR_EXTERNAL, cv2.CHAIN_APPROX_NONE)
```

`RETR_EXTERNAL` keeps only outer contours — pillars are solid objects with simple silhouettes; nested contours are usually irrelevant. `CHAIN_APPROX_NONE` retains full boundary detail so the subsequent `approxPolyDP` has enough points to create a stable approximation.

### Bounding Rectangles and Simple Distance Proxy

Each contour is approximated and bounded to compute the center, area, and a quick pixel-distance estimate.

```python
approx = cv2.approxPolyDP(cnt, 0.01 * cv2.arcLength(cnt, True), True)
x, y, w, h = cv2.boundingRect(approx)
pillar_cx, pillar_cy = x + w//2, y + h//2
pillar_area = w * h
pillar_distance = math.dist([pillar_cx, pillar_cy], [WIDTH//2, HEIGHT])  # e.g., [320,480]
```

This pixel Euclidean distance is not a true metric distance, but it works well for prioritizing the closest. It is a simplistic measurement that avoids the complexity of depth calculations.

**Debugging helper:** the code draws bounding boxes and a centroid point during development to validate thresholds:

```python
cv2.rectangle(im, (x,y), (x+w, y+h), (0,255,255), 2)
cv2.circle(im, (pillar_cx, pillar_cy), 3, (255,0,0), -1)
```

---

## 2. Pillar Filtering and Prioritization

Detection must be filtered aggressively to avoid misbehavior when the track has textures or reflections.

### Area & Size Filtering

Small contours are discarded early to reduce noise:

```python
area = cv2.contourArea(cnt)
if area <= PILLAR_SIZE:
    continue  # too small to be a pillar
```

`PILLAR_SIZE` acts as a low-pass filter on contour area. It's tuned so that slivers of printed texture on the mat don't trigger a reaction while still catching genuine pillars at a useful distance.

### Distance Threshold

Very distant detections are ignored, so the control logic only reacts to immediate obstacles:

```python
if pillar_distance >= 500:
    continue  # pillar is too far to react to reliably
```

This window balances early reaction with false-trigger reduction. Too large a window causes erratic steering, too small makes the robot late to avoid.

### Top/Bottom Edge Rejection

Exclude contours where the bounding box sits too close to the top or bottom of the frame (unreliable zones):

```python
if y + h > 450 or y + h < 125:
    continue
```

- Bottom zone (>450 px) often means the robot has already passed the pillar or the contour is partially out of frame.
- Top zone (<125 px) indicates the pillar is far, and area/centroid estimation is noisy.

### Closest-First Prioritization

From the remaining candidates, the closest pillar by pixel distance is stored as the active avoidance target:

```python
if pillar_distance < closest_pillar_distance:
    closest_pillar_distance = pillar_distance
    closest_pillar_colour = "red"  # or "green" depending on mask
    closest_pillar_x = pillar_cx
    closest_pillar_y = pillar_cy
    closest_pillar_area = pillar_area
```

Choosing the closest pillar ensures the robot focuses on imminent obstacles instead of distant ones that will be handled later. This simplifies decision-making in sections with two pillars.

Pillar decision flow:

```mermaid
flowchart TD
    A[Raw contours] --> B{Area > PILLAR_SIZE?}
    B -->|No| Z[Discard]
    B -->|Yes| C{Distance < 500?}
    C -->|No| Z
    C -->|Yes| D{Y bounds OK?}
    D -->|No| Z
    D -->|Yes| E[Candidate => compare distance]
    E --> F[Keep closest pillar]
```

---

## 3. Steering and Control

This section explains how the chosen pillar is converted to steering commands using a PD controller and how the servo command is converted to PWM for the vehicle.

### Target Alignment — color-specific targets

Targets are fixed X-coordinates that represent where a pillar should appear in the camera frame when the robot passes it on the correct side:

```python
red_target = 120   # desired x for red pillars (left side of camera)
green_target = 520 # desired x for green pillars (right side of camera)

if closest_pillar_colour == "red":
    target = red_target
elif closest_pillar_colour == "green":
    target = green_target
else:
    target = None
```

Using fixed pixel targets is a simple heuristic that ensures the pillar is pushed towards the correct side of the frame. It works well when camera FOV and mounting are consistent.

### Error computation and PD steering

Calculate horizontal error based on the target-x and pillar-x, and apply PD control:

```python
error = target - closest_pillar_x
p_term = error * OBSTACLEPG * MAX_TURN_DEGREE
d_term = (error - prev_pillar_error) * OBSTACLEPD
servo_angle = MID_SERVO - p_term - d_term
prev_pillar_error = error
```

- `OBSTACLEPG` controls responsiveness.
- `OBSTACLEPD` damps oscillations.
- `MAX_TURN_DEGREE` normalizes the error into a fraction of the maximum turn.

**Clamp and convert to PWM** (important for safety):

```python
if servo_angle > MID_SERVO + MAX_TURN_DEGREE:
    servo_angle = MID_SERVO + MAX_TURN_DEGREE
if servo_angle < MID_SERVO - MAX_TURN_DEGREE:
    servo_angle = MID_SERVO - MAX_TURN_DEGREE

pw = pwm(servo_angle)
board.pwm_servo_set_position(0.04, [[1, pw]])  # send servo command
```

PD-only control avoid is sufficient for steering where the steady-state offset is small because the environment provides visual feedback to recentre the pillar. Gains were tuned experimentally on the track; if the robot oscillates, reduce `OBSTACLEPG` or increase `OBSTACLEPD`.

### Optional depth-based gain (Y-axis influence)

The code contains a hook to modify steering intensity based on pillar Y (vertical position = depth proxy):

```python
# Optional depth-dependent adjustment:
servo_angle -= closest_pillar_y * YAXISPG  # applied for green pillars
# YAXISPG is 0 by default; set positive to reduce sensitivity for farther pillars
```

Enabling `YAXISPG` can make the robot steer more aggressively for near pillars while staying calmer for distant ones. 

---

## 4. Emergency Collision Handling

When a pillar fills the frame (a large area), it means that the pillar is very close. If the pillar is not on the correct side of the robot, we must avoid pushing forward into a collision. This triggers an emergency maneuver where the robot reverses in order to avoid the pillar.

Example red pillar:

```python
if closest_pillar_area > 7000 and closest_pillar_distance < 300 and not exit_parking_lot and closest_pillar_x > 250:
    # Straighten and stop, then do a short forward nudge to reposition
    servo_angle = MID_SERVO
    board.pwm_servo_set_position(0.04, [[2, 1500]])  # stop ESC
    board.pwm_servo_set_position(0.04, [[1, pwm(servo_angle)]])
    board.pwm_servo_set_position(0.04, [[2, 1620]])  # small forward nudge
    time.sleep(1)
    board.pwm_servo_set_position(0.04, [[2, DC_SPEED]])  # resume driving
```

The parameters (7000 area,  300 distance, 250 pillar-x) were chosen to catch close pillars while avoiding any false activations.

---

## 5. Edge Case Handling

This section documents several special-case situations the code guards against and includes short code snippets integrated into the relevant logic.

### Interior Wall / Corner Danger

Problem: A pillar might require steering that pushes the robot into an interior wall near corners. The code detects significant wall presence and overrides pillar steering when necessary. This occurs when driving counter-clockwise with an interior green pillar and clockwise with an interior red pillar.

```python
# If green pillar would push robot left into a wall, override.
if (track_dir == "left" and target == green_target and left_area > 10000 and
        closest_pillar_distance > 315):
    servo_angle = MID_SERVO - MAX_TURN_DEGREE
```

`left_area` is measured from a left ROI that senses the inner wall. The `closest_pillar_distance > 315` requirement avoids overriding when the pillar is close (where immediate avoidance is the primary focus).

### Front Area Override (Perpendicular Approaches / Parking Exit)

When the robot is approaching a wall head-on (during the parking lot exit), the front black ROI triggers a stronger avoidance:

```python
if front_area_black > 250 and turn_counter == 0 and target == None:
    servo_angle = MID_SERVO + MAX_TURN_DEGREE
```

`turn_counter == 0` is used because this scenario is only relevant immediately after leaving the parking lot. The front ROI is tuned to detect large dark areas (the outer walls) and bias the steering away. This override only occurs if no pillar is in the field of view, as following a visible pillar is ideal. 

---

### Front Area Override (Exterior pillar avoidance during turn)

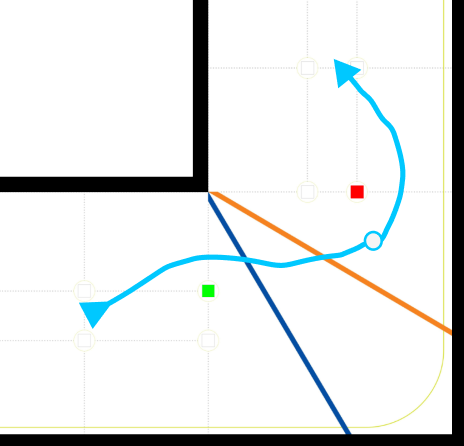
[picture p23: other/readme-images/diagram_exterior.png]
Exterior pillar override


In this pillar combination, the robot must first avoid the green pillar. This results in the position being closer to the interior wall. Then, the robot follows the red pillar target, becoming roughly perpendicular to the exterior wall. As the robot drives forward while attempting to correct the pillar-x, the pillar will leave the camera's field of view. In this case, a manual override must be made to avoid the pillar while turning into the next straight section. 

```python
if front_area_black > 250 and turn_counter > 0 and left_wall > 1000 and target == None:
    servo_angle = MID_SERVO - MAX_TURN_DEGREE
```

The forced correction only occurs if both the left wall ROI and the front ROI detect a black area, allowing the override to selectively occur if the wall is not on the correct side of the robot.

---

## 6. Turn Handling, Line Detection, and Lap Counting

This logic transitions the vehicle between straight sections and turns and is essential for lap counting. When there are no pillars that need to be avoided, the logic allows the robot to stay within the middle of each section to prepare for future pillars.

Additionally, this code is used for the complete logic in the open challenge. 

### Blue & Orange Line Detection (turn triggers)

Short ROI-based detections detect corners based on the first coloured line:

```python
if blue_line_area >= LINE_THRESHOLD and track_dir != "right" and not seen_line:
    track_dir = "left"
    turn_dir = "left"
    seen_line = True
    turn_counter += 1

if orange_line_area >= LINE_THRESHOLD and track_dir != "left" and not seen_line:
    track_dir = "right"
    turn_dir = "right"
    seen_line = True
    turn_counter += 1
```

The `seen_line` flag prevents multiple counts for the same physical line as the robot passes the ROI over several frames.

### End-of-turn detection

During a turn, the code monitors for the opposite color line and wall area thresholds to determine the end of the turn and transition back to straight-line wall following.

```python
if turn_dir == "left" and orange_line_area >= LINE_THRESHOLD:
    line_end = True
if turn_dir == "right" and blue_line_area >= LINE_THRESHOLD:
    line_end = True
```

### Wall-based fallback navigation

When no pillar or lines are available, the vehicle uses left/right wall area differences for steering:

```python
current_difference = left_area - right_area
servo_angle = MID_SERVO + (current_difference * PG + (current_difference - last_difference) * PD)
last_difference = current_difference
```

This PD on areas effectively centers the vehicle between walls. PD avoids long-term drift while being responsive to changes in wall proximity.

### Turn counting

After 12 turns, the robot transitions to parking in the obstacle challenge. In the open challenge, the number of actions is counted after the last turn and once it reaches a certain number, the robot stops. This is to ensure the robot fully stops in the straight section. 

No pillar flowchart:

```mermaid
flowchart TD
    A[Start] --> B{Do we see a blue or orange line ahead?}

    B -->|Blue line & not turn & first time| C[Start a LEFT turn<br/>Mark line as seen<br/>Increase turn counter]
    B -->|Orange line & not turn & first time| D[Start a RIGHT turn<br/>Mark line as seen<br/>Increase turn counter]
    B -->|No line detected| E[Check if turning]

    C --> E
    D --> E

    E -->|Turning LEFT & orange line| F[End of the LEFT turn]
    E -->|Turning RIGHT & blue line| F[End of the RIGHT turn]
    E -->|Still in turn or going straight| G[Keep turning or go straight]

    F --> H[Turn is finished<br/>Reset turn direction<br/>Allow new line detection]
    H --> I[Resume normal driving]

    G --> I

    I --> J{Any pillars to follow?}
    J -->|Yes| K[Avoid pillars]
    J -->|No| L[Use wall-following]

    L --> M[Compare left & right walls]
    M --> N[Adjust steering]
    N --> O[Remember this difference]
```

---

## 7. Exiting the Parking Lot

The robot must exit the parking lot safely and deterministically. The code sets exit flags at the beginning and executes small routines to clear the lot.

### Deciding Direction

At the start, the robot measures the left and right wall areas and chooses an exit direction:

```python
if startFromParkingLot:
    if left_area > right_area:
        track_dir = "right"
        exit_parking_lot_right = True
    else:
        track_dir = "left"
        exit_parking_lot_left = True
    startFromParkingLot = False
```

Using the immediate camera observation avoids dependence on any external configuration and adapts to the random configuration.

### Exit routine example

```python
if exit_parking_lot_left:
    # steer left for a short burst, apply thrust, straighten
    board.pwm_servo_set_position(0.04, [[1, pwm(0)]])
    board.pwm_servo_set_position(0.04, [[2, DC_SPEED + 5]])
    time.sleep(0.8)
    board.pwm_servo_set_position(0.04, [[1, pwm(MID_SERVO)]])
    exit_parking_lot_left = False
```

The timed DC burst allows the robot to precisely navigate out of the tight parking lot.

---

## 8. Parking Sequence

Our parking sequence utilizes the **LD19 D500 Lidar** to precisely detect both the parking walls and the outer black boundary walls. In order to get to a fixed position near the parking lot, the robot follows the black walls using the lidar. 

The code periodically aggregates LIDAR points and tries to fit the inner wall with a least-squares line. It filters points with `filter_wall_points` so that only points expected to belong to the wall are used, then computes slope and a corresponding angle error (the difference between the robot heading and the wall angle). When enough points are found, the code nudges the steering to correct alignment using the computed `angle_error`.

```python
wall_points = filter_wall_points(current_scan_points, x_min=-4, x_max=4, y_min=-100, y_max=-5)
slope, angle_error, status = calculate_wall_slope_and_error(wall_points)
servo_angle = MID_SERVO + (angle_error * LIDARPG)
```

`filter_wall_points` selects points that fall in a fixed box in robot coordinates; `calculate_wall_slope_and_error` uses a least-squares fit to find a line and converts that slope into a small angular correction. The multiplier `LIDARPG` scales that computed correction to a steering command. The result is a closed-loop LIDAR-guided alignment while the robot drives slowly into the parking lot.

---

Our algorithm has a different maneuver based on the last pillar of the straight section.

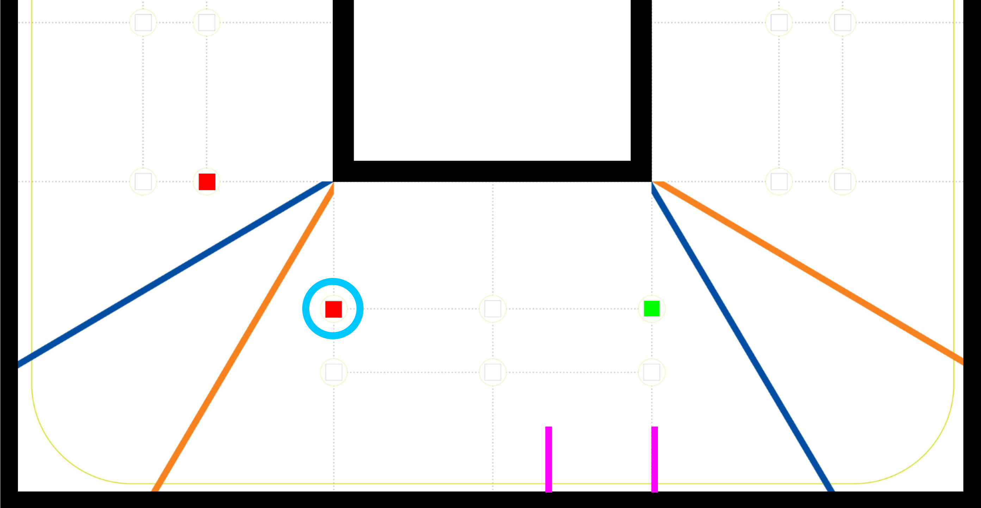
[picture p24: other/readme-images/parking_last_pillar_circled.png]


In this case, the last pillar (circled) is red. Therefore, the robot must pass the pillar on the right. In this case, our robot will follow this procedure:

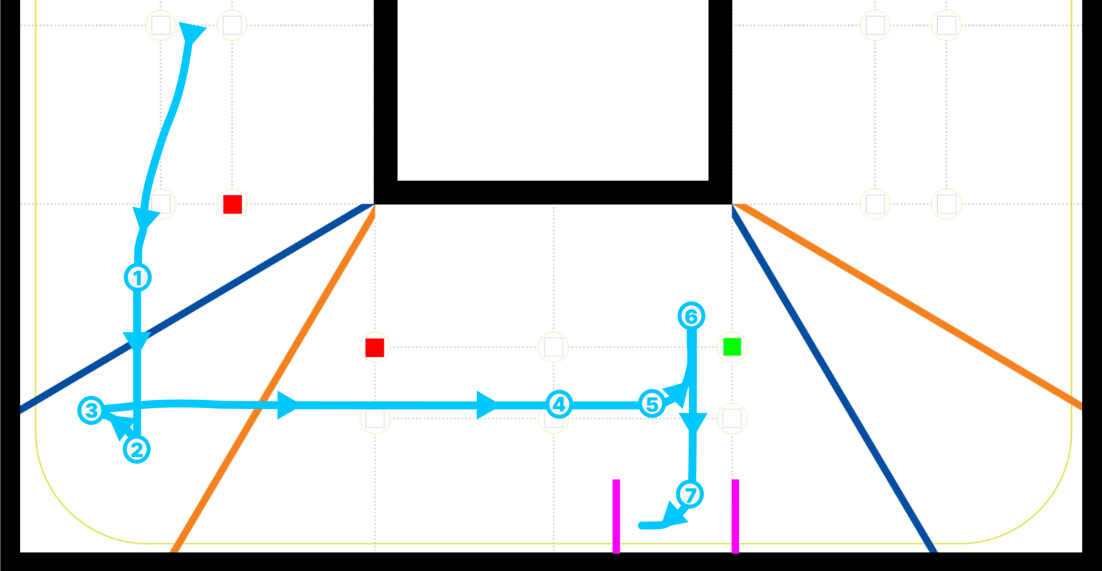
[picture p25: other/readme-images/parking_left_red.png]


1. After the robot detects the blue line, it checks the colour of the last pillar. If the last pillar is red or there is no last pillar, the robot begins to follow the front wall, becoming perpendicular. 
2. The robot continues following the front wall until it is detected to be within 15 centimeters or less.
3. The robot enters a timed 90-degree reverse turn.
4. The robot follows the right wall until the first parking lot wall is detected.
5. The robot sets the servo to the straight position and moves forward until the second parking lot wall is detected. Then, the robot takes a timed turn right.
6. The robot reverses while adjusting to become perpendicular to the wall in front.
7. Once the distance to the front wall exceeds 65 centimeters, the robot starts a reverse turn to become parallel.

If the last pillar is green, the robot will first pass the green pillar, then turn into the exterior wall and perform the red pillar sequence.

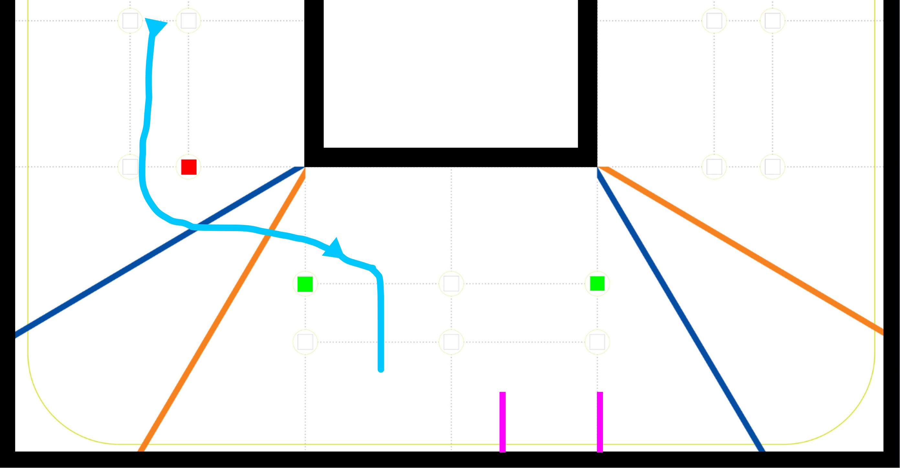
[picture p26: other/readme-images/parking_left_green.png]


This sequence is simply inverted for the opposite track direction if there is no last pillar or if it is green. 

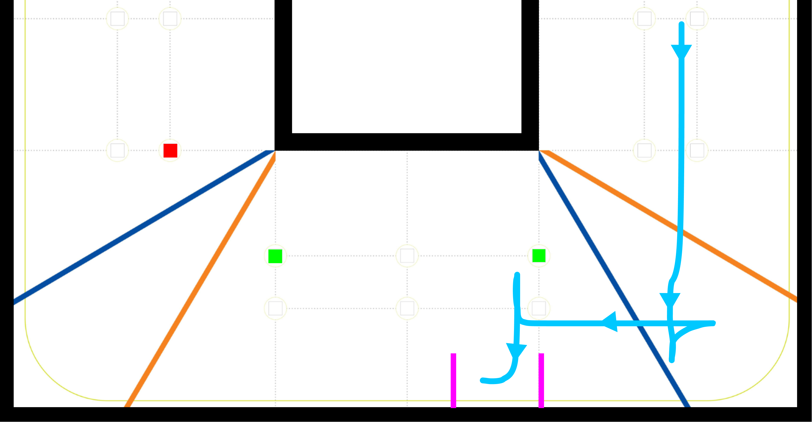
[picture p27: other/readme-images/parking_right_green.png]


If the last pillar is red, the robot passes the red pillar and follows the interior wall to become parallel. Then it reverses and makes a 90-degree right turn. Then, it uses the normal parking sequence. 

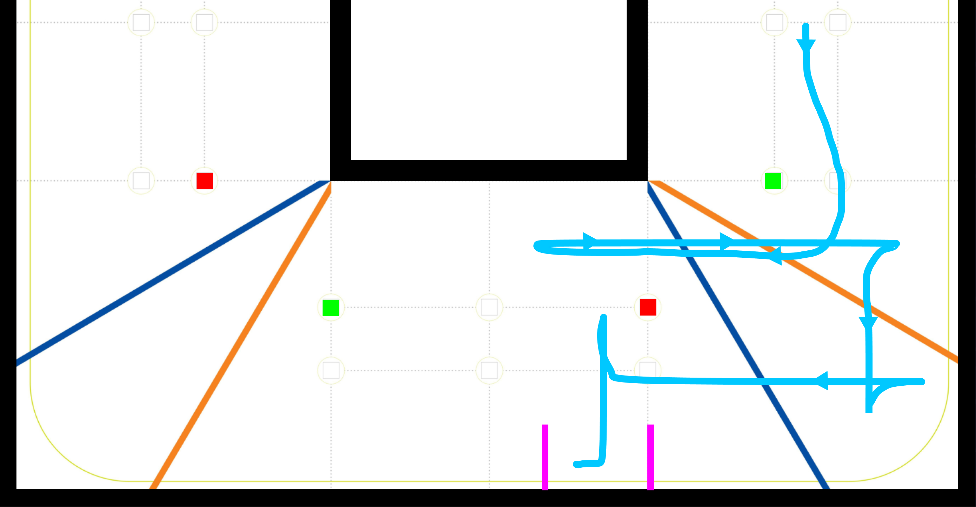
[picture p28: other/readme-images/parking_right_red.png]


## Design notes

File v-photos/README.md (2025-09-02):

Vehicle's photos
====

This directory contains six photos of the vehicle (from every side, as well as from top and bottom), as well as a labeled diagram of the core chassis.

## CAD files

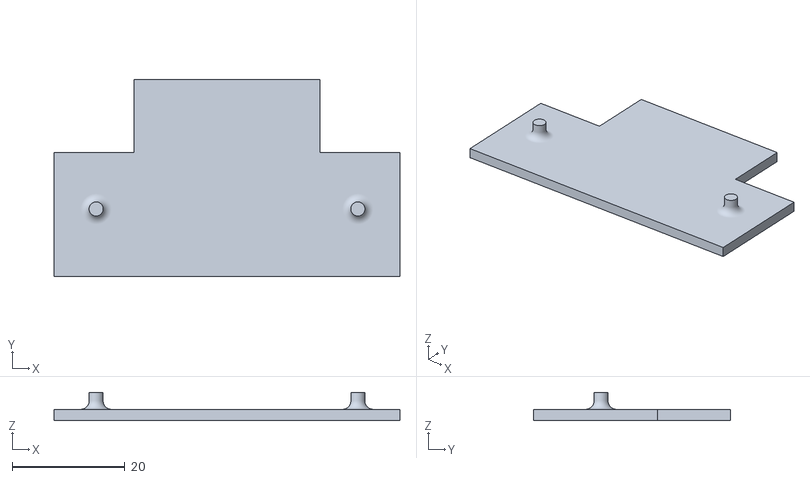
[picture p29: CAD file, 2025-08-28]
models/lidhold.stl
61.5 x 35.0 x 5.00

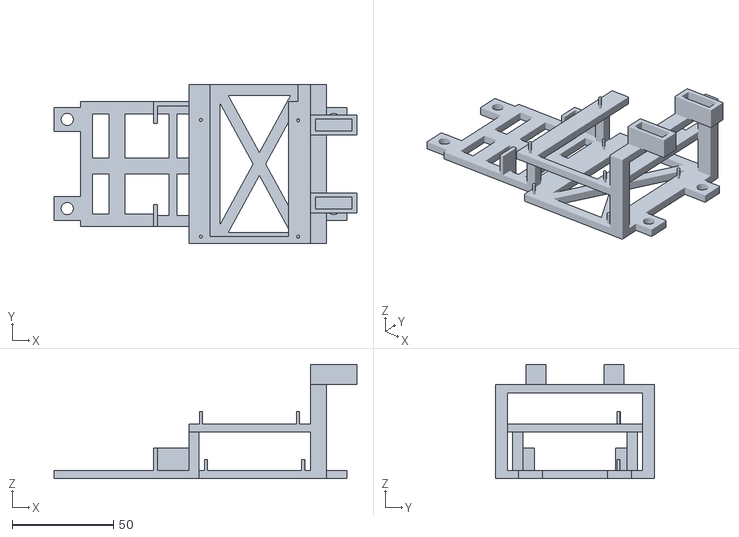
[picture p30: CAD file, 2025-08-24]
models/platform 3 Copy 2.stl
149.5 x 78.7 x 56.4

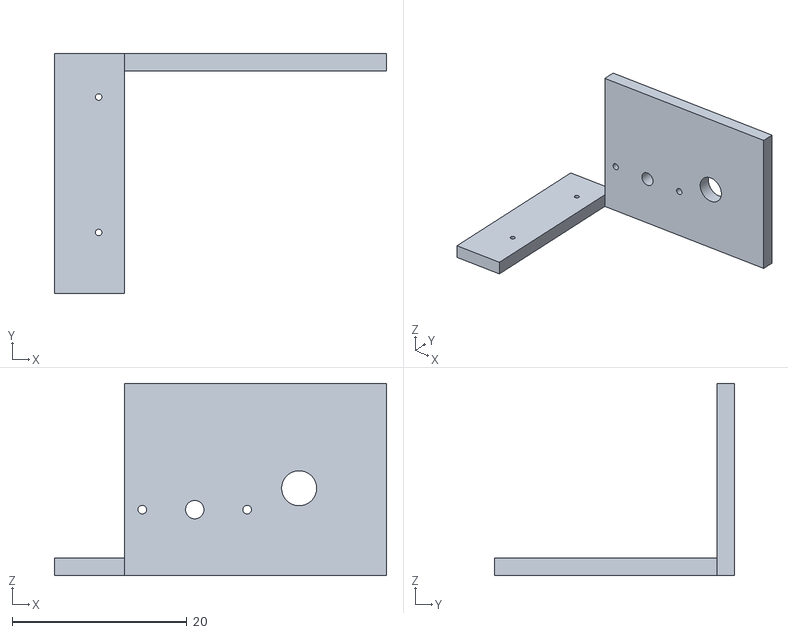
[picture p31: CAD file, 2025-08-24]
models/motormount.stl
38.0 x 27.5 x 22.0

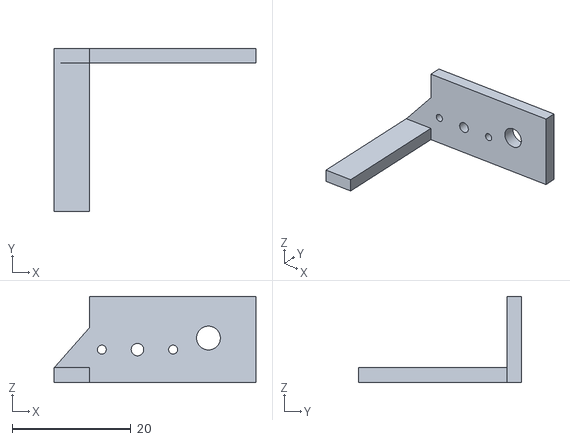
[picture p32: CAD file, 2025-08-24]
models/motormount3.stl
34.0 x 27.5 x 14.5

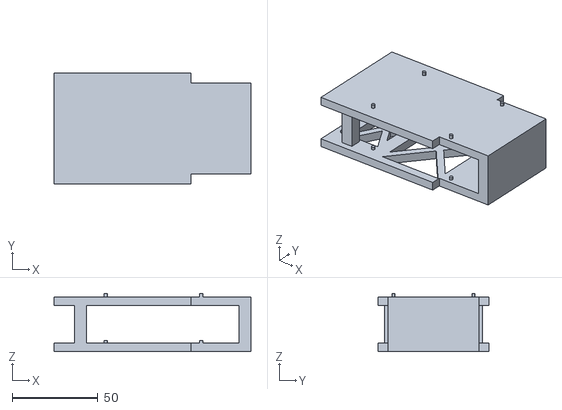
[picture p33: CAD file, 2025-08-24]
models/p1.stl
115.0 x 65.0 x 34.0

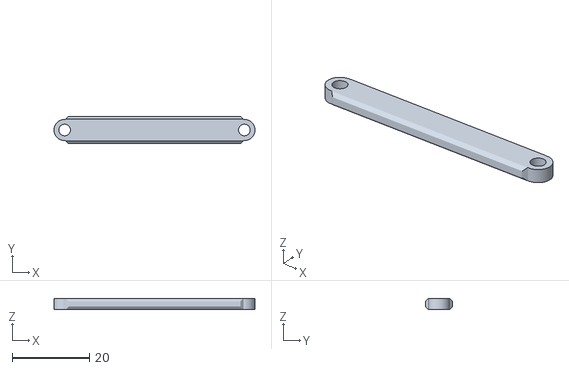
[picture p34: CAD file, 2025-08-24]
models/steer.stl
52.0 x 7.00 x 2.80

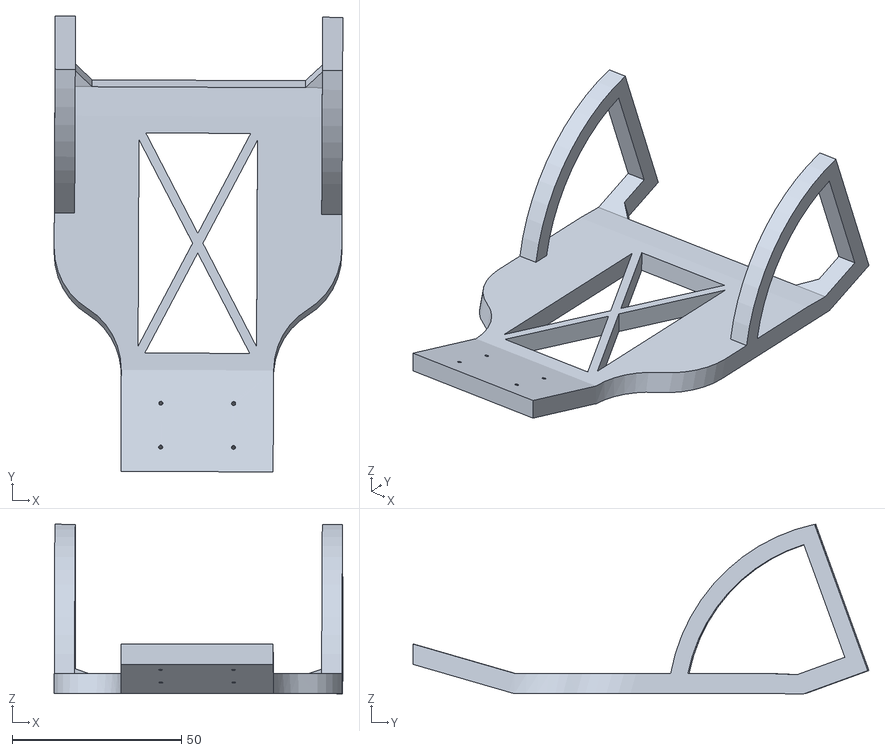
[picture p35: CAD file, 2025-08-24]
models/Camera_Mount_V2.stl
85.3 x 134.7 x 50.1

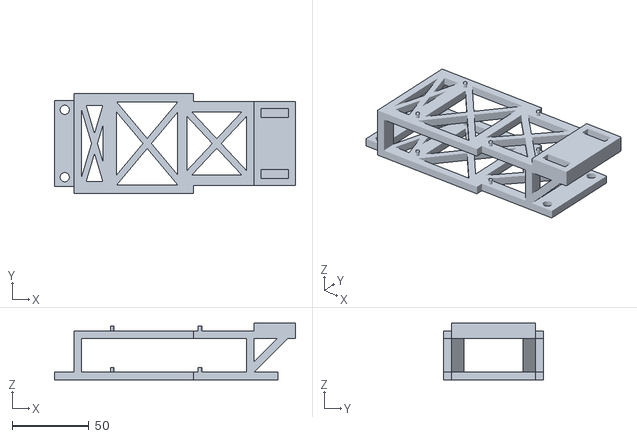
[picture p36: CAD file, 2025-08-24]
models/Part Studio 1.stl
157.3 x 65.0 x 37.0

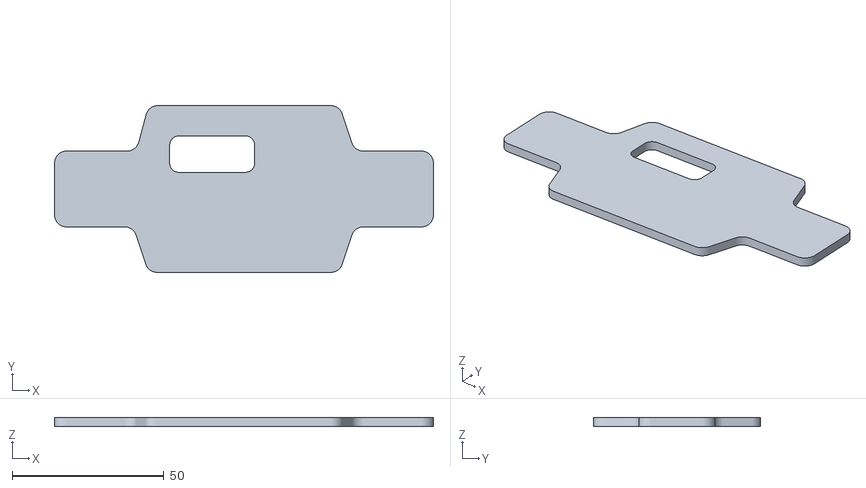
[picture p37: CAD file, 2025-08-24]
models/chassis2.stl
125.0 x 55.0 x 3.00

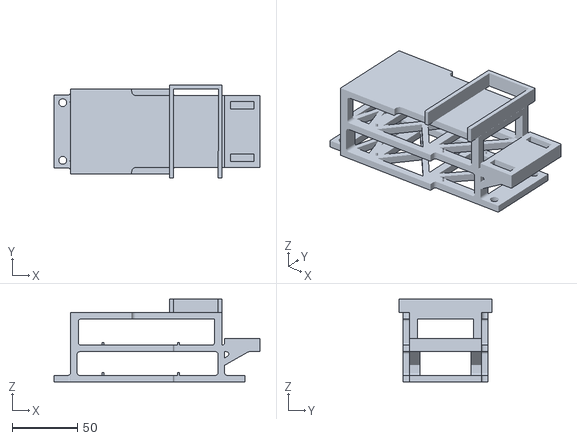
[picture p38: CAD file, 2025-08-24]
models/platform.stl
157.3 x 71.0 x 63.2

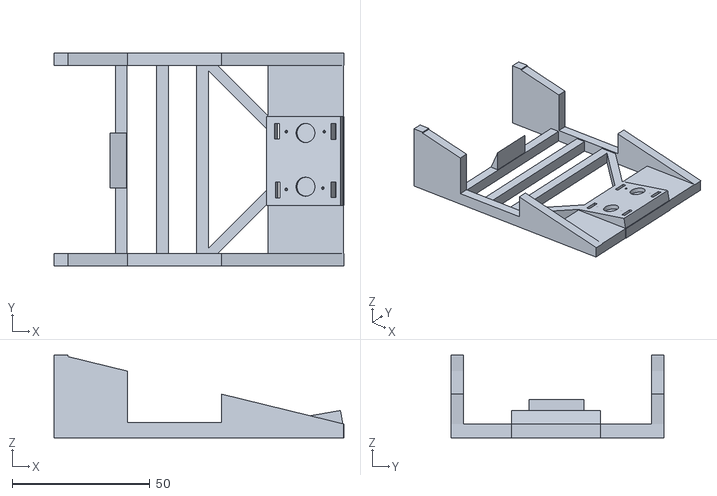
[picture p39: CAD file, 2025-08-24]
models/camera holder v6.stl
105.2 x 77.2 x 30.0

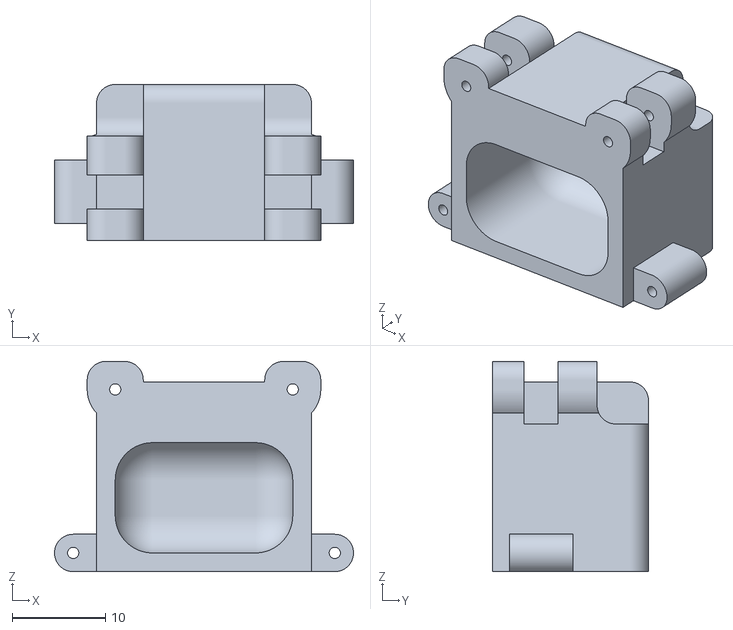
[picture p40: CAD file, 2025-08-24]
models/front2.stl
32.0 x 16.7 x 22.5

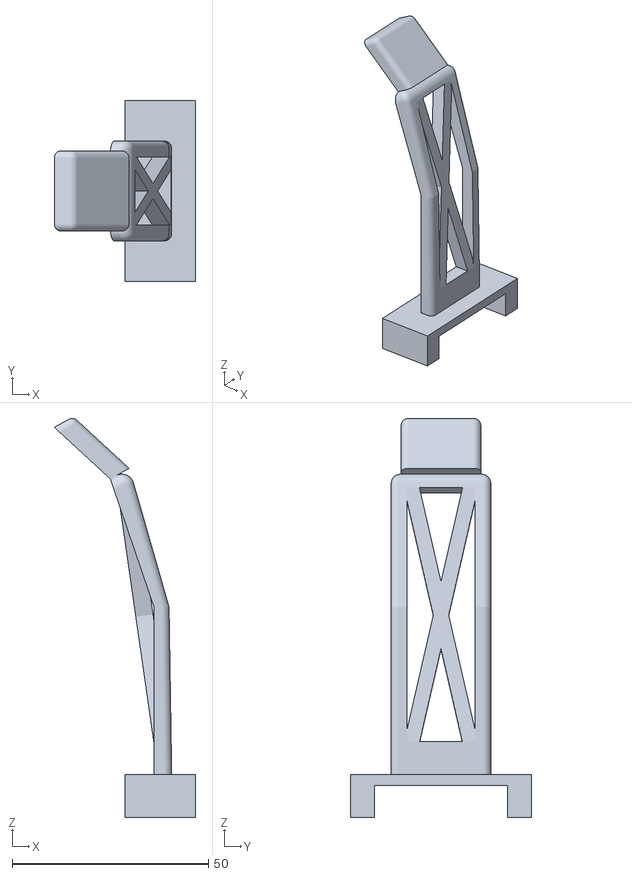
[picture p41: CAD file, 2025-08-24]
models/camera.stl
36.0 x 46.0 x 101.6

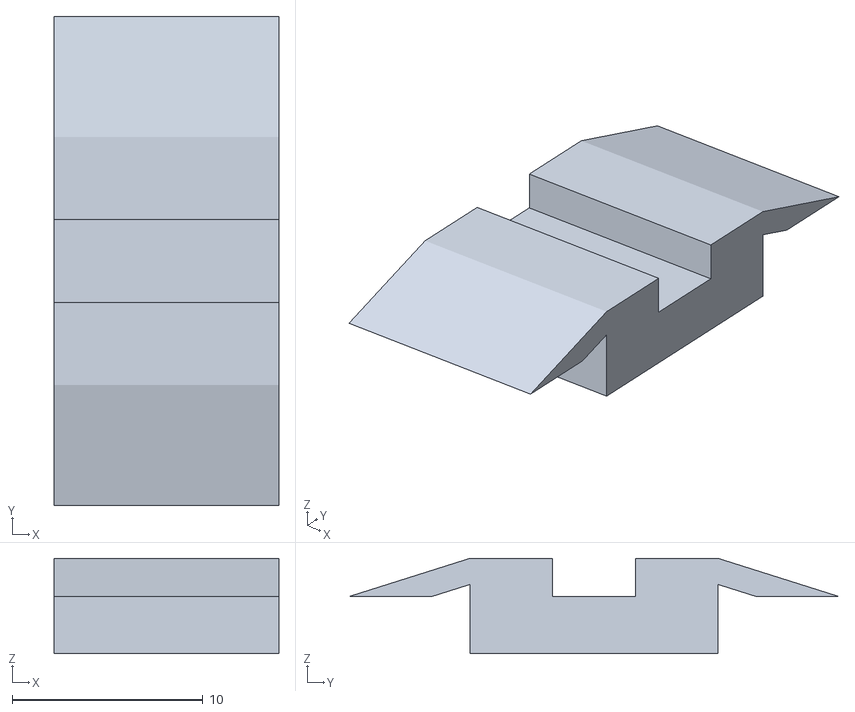
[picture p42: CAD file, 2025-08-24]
models/holder3.stl
11.8 x 25.7 x 5.00

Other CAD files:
models/platform 4.stl
models/wheel holder.stl
models/front3.stl
models/platformholder2.stl
models/base.stl
models/baseplate3.stl
models/cam.stl
models/cam2.stl
models/cameraholder3.stl
models/connect.stl
models/front.stl
models/p2.stl
models/p3.stl
models/platform2.stl
models/platform3.stl
models/steeringrod2.stl
models/unused/baseplate1.stl
models/unused/cameraholder1.stl
models/unused/cameraholder2.stl
models/unused/front.stl
models/unused/front3.stl
models/unused/platform2.stl
models/unused/platform3.stl
models/unused/platform4.stl
models/unused/platformholder1.stl
models/unused/wheeholder2.stl
models/unused/wheelholder1.stl
models/unused/wheelholder3.stl
models/wheel holder (1).stl
models/wheel holder Copy 1.stl
models/wheelholder7.stl

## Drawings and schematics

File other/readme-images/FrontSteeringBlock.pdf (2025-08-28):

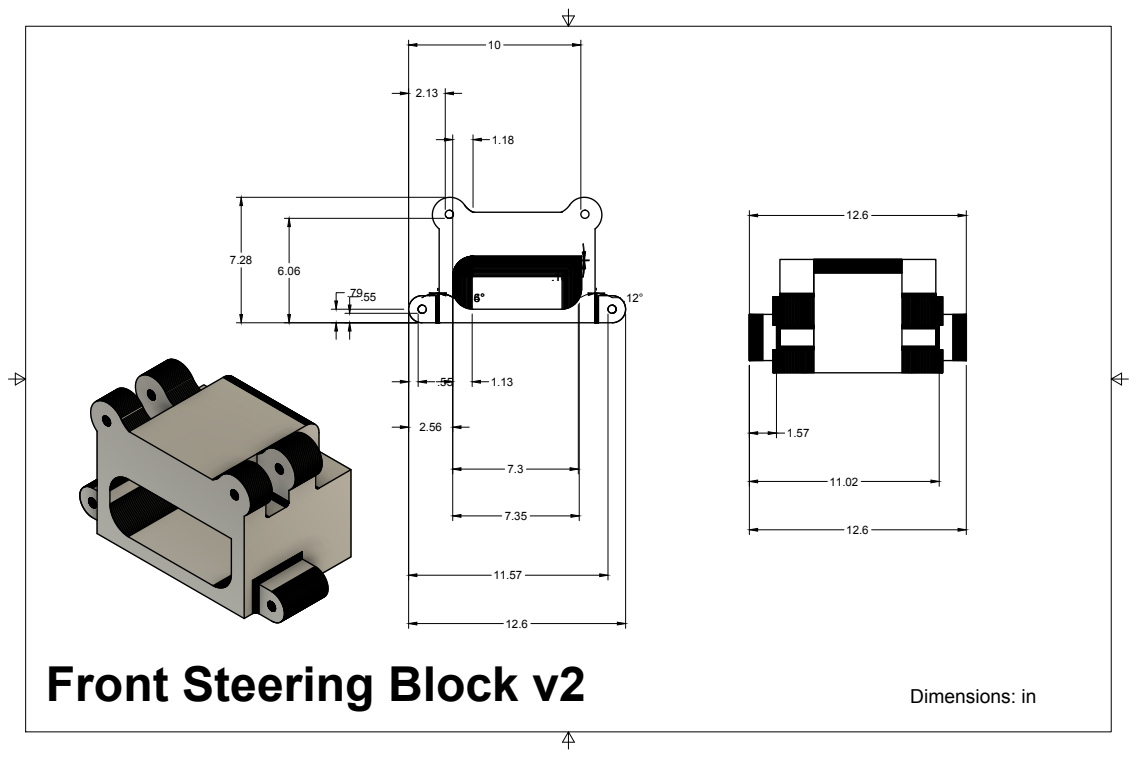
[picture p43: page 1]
Front Steering Block v2; Dimensions: in

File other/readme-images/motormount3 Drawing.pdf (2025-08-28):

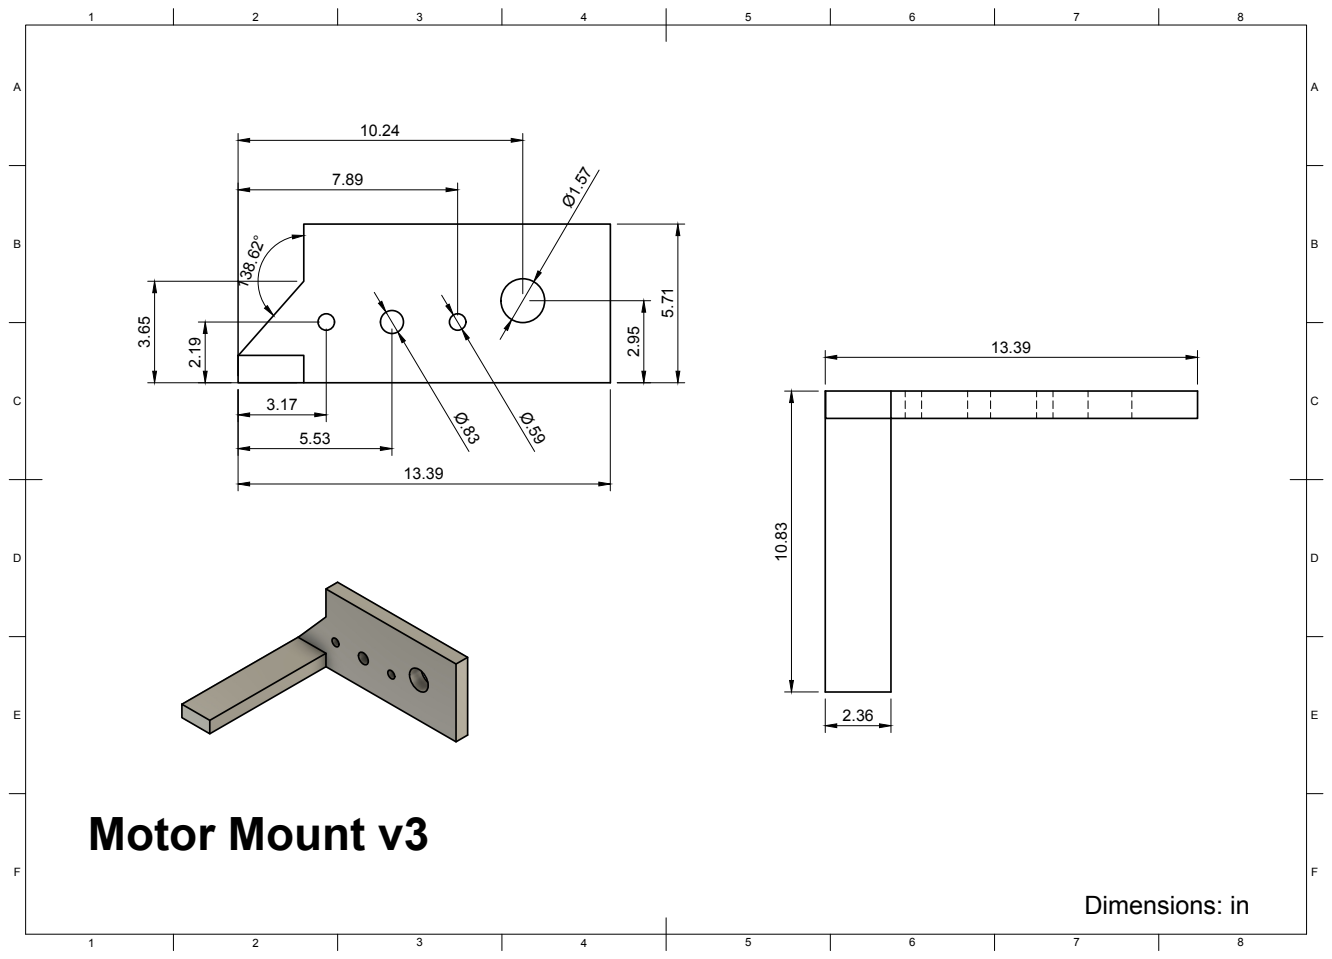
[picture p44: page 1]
Dimensions: in; Motor Mount v3

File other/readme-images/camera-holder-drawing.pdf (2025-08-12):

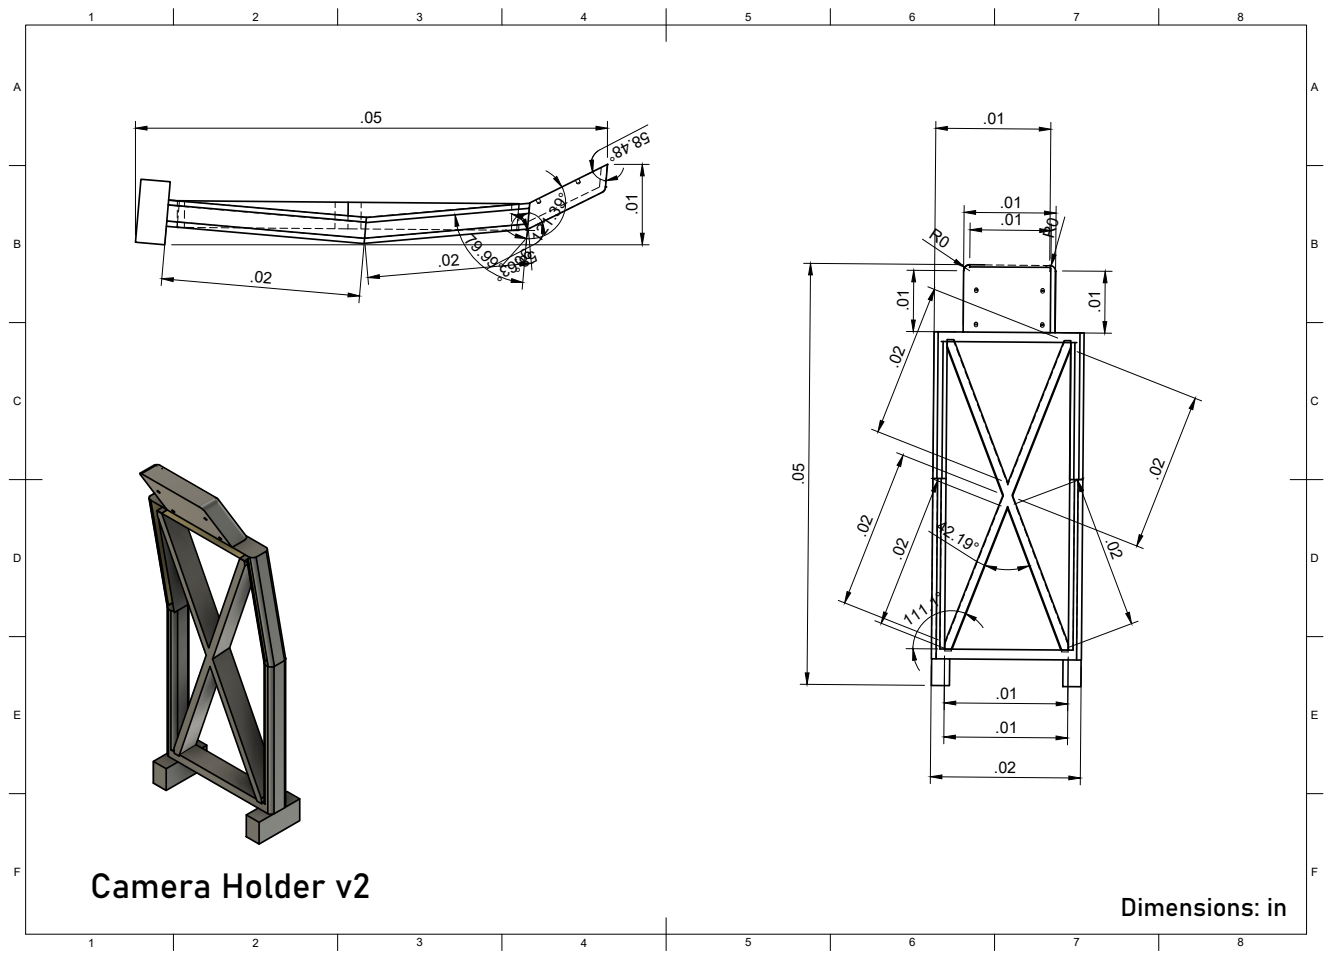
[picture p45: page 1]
Camera Holder v2; Dimensions: in

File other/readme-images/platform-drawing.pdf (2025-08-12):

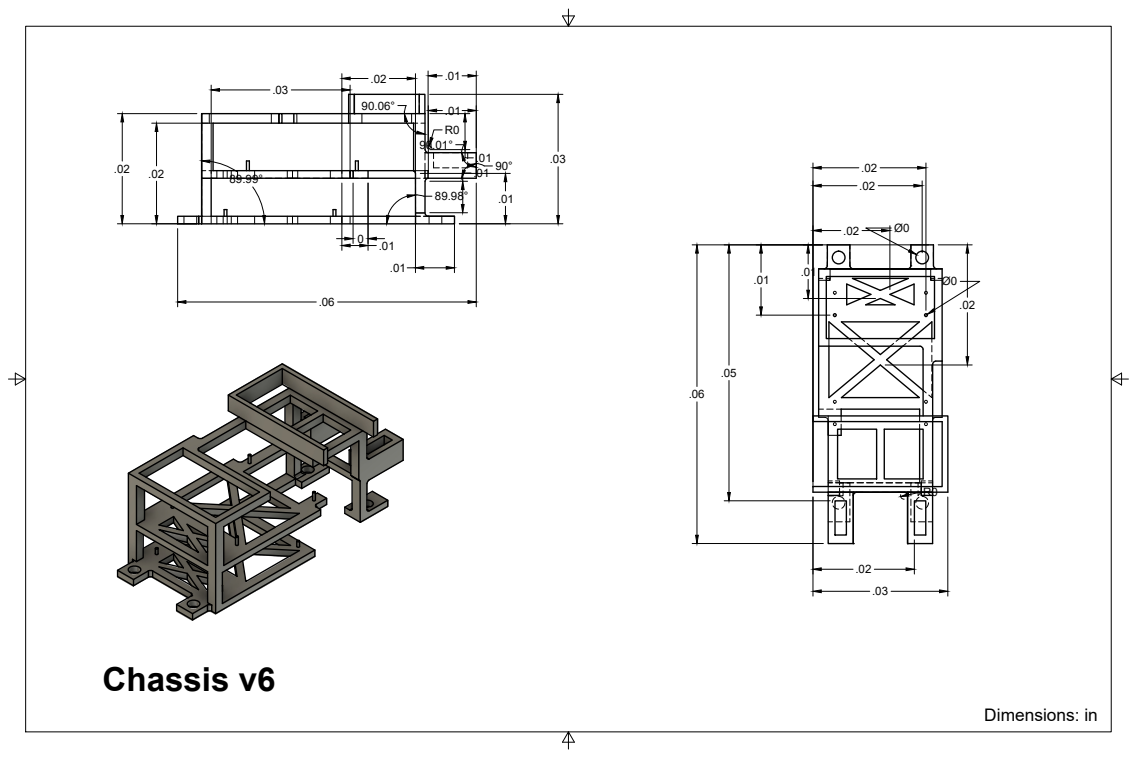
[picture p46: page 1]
Chassis v6; Dimensions: in

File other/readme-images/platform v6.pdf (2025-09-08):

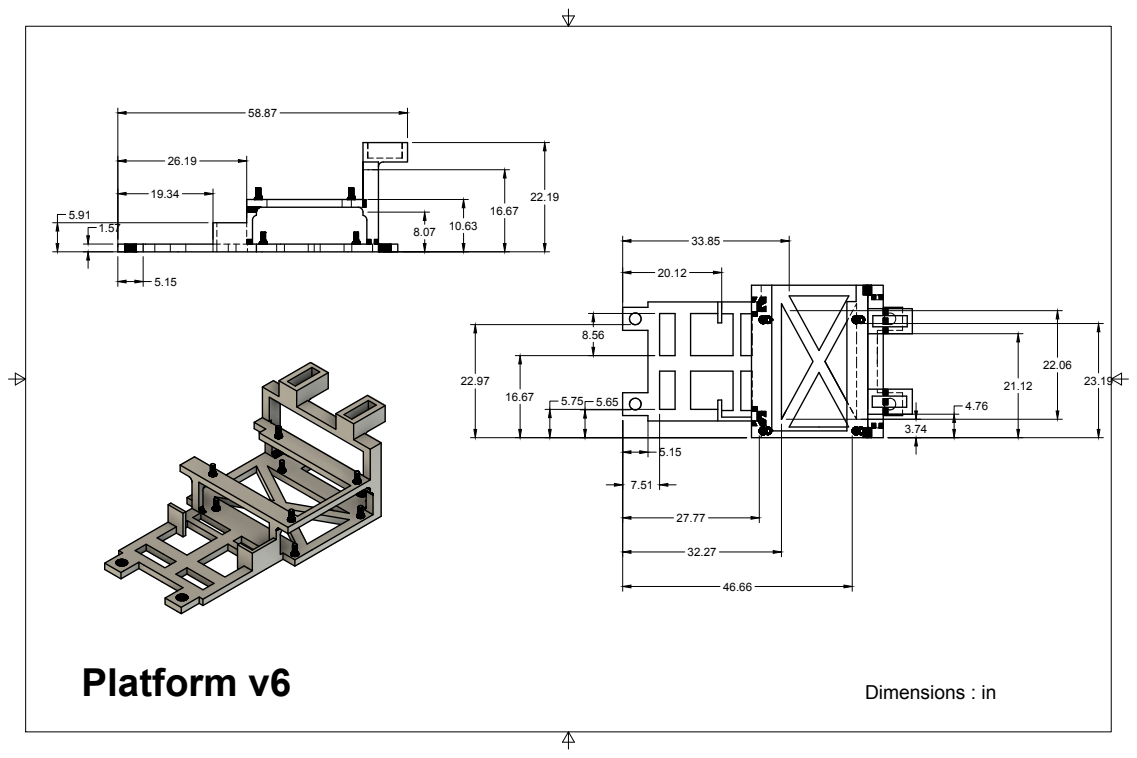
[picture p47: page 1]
Platform v6; Dimensions : in

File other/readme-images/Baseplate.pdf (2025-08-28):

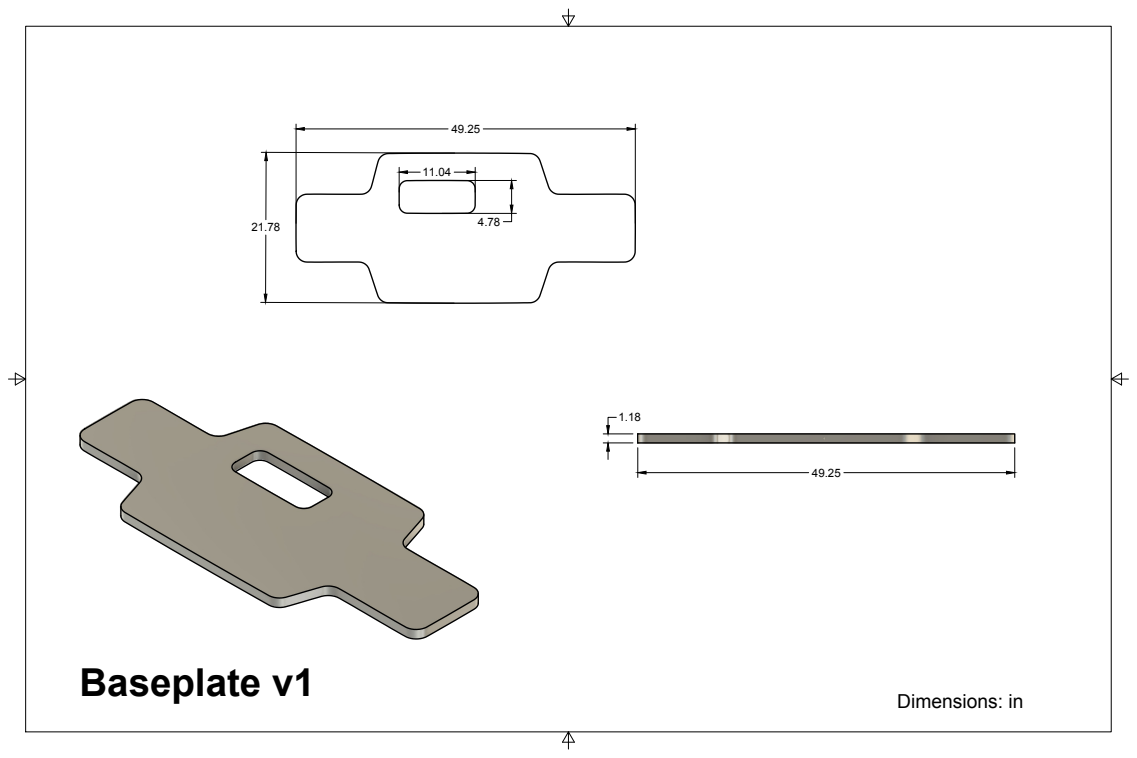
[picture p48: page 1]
Baseplate v1; Dimensions: in

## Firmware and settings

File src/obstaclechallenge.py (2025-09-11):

import cv2
import numpy as np
import time
import ros_robot_controller_sdk as rrc
import math
import os
from picamera2 import Picamera2
import RPi.GPIO as GPIO
import subprocess
import threading

# Imports for LD19 LIDAR parsing
import serial
import struct

board = rrc.Board()
BUTTON_ID_1 = 1
BUTTON_ID_2 = 2
MID_SERVO = 63
MAX_TURN_DEGREE = 33
DC_SPEED = 1376
PILLAR_SIZE = 400
PD = 0.0025
PG = 0.0025
LIDARPG = 0.8
ROI_LEFT = [0, 210, 100, 470]
ROI_RIGHT = [540, 210, 640, 470]
ROI_LINE = [240, 380, 400, 400]
ROI_MIDDLE = [0, 200, 640, 400]
ROI_FRONT = [280, 240, 360, 270]
LOWER_BLACK_THRESHOLD = np.array([0, 0, 0])
UPPER_BLACK_THRESHOLD = np.array([180, 255, 90])

LOWER_RED_THRESHOLD1 = np.array([0, 154, 50])
UPPER_RED_THRESHOLD1 = np.array([6, 255, 255])
LOWER_RED_THRESHOLD2 = np.array([175, 180, 50])
UPPER_RED_THRESHOLD2 = np.array([180, 255, 255])

# LOWER_GREEN_THRESHOLD = np.array([65, 90, 35])
# UPPER_GREEN_THRESHOLD = np.array([85, 255, 185])
LOWER_GREEN_THRESHOLD = np.array([65, 90, 56])
UPPER_GREEN_THRESHOLD = np.array([88, 255, 185])
LOWER_ORANGE_THRESHOLD1 = np.array([180, 80, 120])
UPPER_ORANGE_THRESHOLD1 = np.array([180, 255, 255])
LOWER_ORANGE_THRESHOLD2 = np.array([5, 156, 120])
UPPER_ORANGE_THRESHOLD2 = np.array([20, 255, 255])
# LOWER_BLUE_THRESHOLD = np.array([105, 45, 60])
# UPPER_BLUE_THRESHOLD = np.array([130, 255, 200])
LOWER_MAGENTA_THRESHOLD = np.array([150, 150, 70])
UPPER_MAGENTA_THRESHOLD = np.array([172, 255, 255])
LOWER_BLUE_THRESHOLD = np.array([105, 60, 60])
UPPER_BLUE_THRESHOLD = np.array([130, 255, 200])
WIDTH = 640
HEIGHT = 480
POINTS = [(115, 200), (525, 200), (640, 370), (0, 370)]

MAX_TURNS = 12
ACTIONS_TO_STRAIGHT = 120
WALL_THRESHOLD = 200
NO_WALL_THRESHOLD = 200
TURN_ITER_LIMIT = 30
LINE_THRESHOLD = 100
SHOW_CONTOURS = True


action_counter = 0
turn_counter = 0
turn_length_counter = 0
button_pressed = False
close_to_wall = False
right_reading = True
right_reading_2 = True
parking_left = False
startFromParkingLot = True
track_dir = None
done_turning = False
turn_dir = None
last_difference = 0
current_difference = 0
prev_pillar_error = 0
seen_line = False
line_end = False
servo_angle = 0
exit_parking_lot = False
exit_parking_lot_right = False
exit_parking_lot_left = False
exit_parking_lot_red = False
exit_parking_lot_green = False
avoid_phase = False
im = None
image = None
turn_to_parking_section = False
red_target = 120
green_target = 520
gyro = False
at_parking_lot = False
clear = False
stopMove = False
running = True
forward = True
parking_right = False
passed_wall = False
last_green_left_track = False
last_red_right_track = False
stop_after_laps = False
parallel = False

# Add these with your other global variables

previous_angle = None
current_scan_points = []

rotation_count = 0
shared_folder = "/home/pi/docker/tmp"  # Raspberry Pi path
filepath = os.path.join(shared_folder, "imu_data.json")

last_modified = 0


picam2 = Picamera2()
picam2.preview_configuration.main.size = (640, 480)
picam2.preview_configuration.main.format = "RGB888"
picam2.preview_configuration.controls.FrameRate = 30
picam2.configure("preview")
picam2.start()

fps_counter = 0
fps_start_time = time.time()
fps = 0

# LD19 LIDAR Constants
PORT = "/dev/ttyAMA0"
BAUD = 230400
PACKET_HEADER = 0x54
PACKET_LEN = 47

# Initialize serial for LD19
ser = serial.Serial(PORT, BAUD, timeout=0.01)  # Reduced timeout for non-blocking read
buffer = bytearray()


def listen_to_button_events():
    global button_pressed
    command = (
        "source /home/ubuntu/.zshrc && ros2 topic echo /ros_robot_controller/button"
    )
    process = subprocess.Popen(
        [
            "docker",
            "exec",
            "-u",
            "ubuntu",
            "-w",
            "/home/ubuntu",
            "MentorPi",
            "/bin/zsh",
            "-c",
            command,
        ],
        stdout=subprocess.PIPE,
        stderr=subprocess.PIPE,
        text=True,
    )

    while True:
        output = process.stdout.readline()
        if output:
            line = output.strip()
            if line.startswith("id:"):
                button_id = int(line.split(":")[1].strip())
            elif line.startswith("state:"):
                state = int(line.split(":")[1].strip())

                if button_id == 1:
                    if state == 1:
                        button_pressed = True
                        print("Button 1 pressed")
                elif button_id == 2:
                    if state == 1:
                        print("Button 2 pressed")
        else:
            continue


def check_node_status():
    command = "source /home/ubuntu/.zshrc && ros2 topic list"
    result = subprocess.run(
        [
            "docker",
            "exec",
            "-u",
            "ubuntu",
            "-w",
            "/home/ubuntu",
            "MentorPi",
            "/bin/zsh",
            "-c",
            command,
        ],
        capture_output=True,
        text=True,
    )
    res = result.stdout
    return "/ros_robot_controller/button" in res


def find_packet_start(buffer):
    """Find the start index of a valid packet in buffer."""
    for i in range(len(buffer) - 1):
        if buffer[i] == 0x54 and (buffer[i + 1] & 0xFF) == 0x2C:
            return i
    return -1


def parse_packet(packet):
    if len(packet) != PACKET_LEN:
        return None
    speed = struct.unpack_from("<H", packet, 2)[0] / 64.0  # RPM
    start_angle = struct.unpack_from("<H", packet, 4)[0] / 100.0
    measurements = []
    for i in range(12):
        offset = 6 + i * 3
        dist = struct.unpack_from("<H", packet, offset)[0]
        confidence = packet[offset + 2]
        measurements.append((dist, confidence))
    end_angle = struct.unpack_from("<H", packet, 42)[0] / 100.0
    timestamp = struct.unpack_from("<H", packet, 44)[0]
    crc = packet[46]
    return {
        "speed": speed,
        "start_angle": start_angle,
        "end_angle": end_angle,
        "timestamp": timestamp,
        "crc": crc,
        "points": measurements,
    }


def fit_line_least_squares(points):
    if len(points) < 2:
        return None, None
    x_coords = [p[0] for p in points]
    y_coords = [p[1] for p in points]
    n = len(points)
    sum_y, sum_x = sum(y_coords), sum(x_coords)
    sum_xy = sum(x * y for x, y in points)
    sum_yy = sum(y * y for y in y_coords)
    denominator = n * sum_yy - sum_y * sum_y
    if abs(denominator) < 1e-10:
        return None, None
    slope = (n * sum_xy - sum_x * sum_y) / denominator
    intercept = (sum_x - slope * sum_y) / n
    return slope, intercept


def calculate_wall_slope_and_error(wall_points):
    if len(wall_points) < 8:
        return None, None, "Insufficient points"
    slope, intercept = fit_line_least_squares(wall_points)
    if slope is None:
        return None, None, "Could not fit line"
    angle_from_vertical = math.degrees(math.atan(slope))
    return slope, angle_from_vertical, "OK"


def interpolate_angles(start, end, count):
    """Return a list of interpolated angles from start to end over count points."""
    angle_range = (end - start + 360) % 360
    step = angle_range / (count - 1)
    return [(start + i * step) % 360 for i in range(count)]


def pwm(degree):
    return round(degree * 11.1 + 500)


def drawROI(ROI):
    image = cv2.line(im, (ROI[0], ROI[1]), (ROI[2], ROI[1]), (0, 255, 255), 4)
    image = cv2.line(im, (ROI[0], ROI[1]), (ROI[0], ROI[3]), (0, 255, 255), 4)
    image = cv2.line(im, (ROI[2], ROI[3]), (ROI[2], ROI[1]), (0, 255, 255), 4)
    image = cv2.line(im, (ROI[2], ROI[3]), (ROI[0], ROI[3]), (0, 255, 255), 4)


def stop():

    board.pwm_servo_set_position(0.04, [[2, 1500]])
    board.pwm_servo_set_position(0.04, [[1, pwm(MID_SERVO)]])
    time.sleep(0.1)
    board.pwm_servo_set_position(0.04, [[2, 1500]])

    cv2.destroyAllWindows()


def findMaxContour(contours):
    max_area = 0
    for i in range(len(contours)):
        area = cv2.contourArea(contours[i])
        max_area = max(area, max_area)
    return max_area


def detect_angle_reset(current_angle, previous_angle):
    if previous_angle is None:
        return False
    return previous_angle > 300 and current_angle < 60


def filter_wall_points(points, x_min=20, x_max=100, y_min=-25, y_max=0):
    wall_points = []
    for x, y in points:
        if x_min <= x <= x_max and y_min <= y <= y_max:
            wall_points.append((x, y))
    return wall_points


board.pwm_servo_set_position(0.04, [[2, 1500]])


board.pwm_servo_set_position(0.04, [[1, pwm(MID_SERVO)]])
board.pwm_servo_set_position(0.04, [[2, 1500]])
time.sleep(1)


if check_node_status():
    print("ROS2 node detected")
    listener_thread = threading.Thread(target=listen_to_button_events, daemon=True)
    listener_thread.start()
    while not button_pressed:
        pass

time.sleep(1)
if not startFromParkingLot:
    board.pwm_servo_set_position(0.04, [[2, DC_SPEED]])
a = False


while True:

    if (
        exit_parking_lot_green
        or exit_parking_lot_red
        or exit_parking_lot_left
        or exit_parking_lot_right
    ):
        exit_parking_lot = True
    else:
        exit_parking_lot = False

    im = picam2.capture_array()
    input = np.float32(POINTS)
    output = np.float32(
        [(0, 0), (WIDTH - 1, 0), (WIDTH - 1, HEIGHT - 1), (0, HEIGHT - 1)]
    )

    img_hsv = cv2.cvtColor(im, cv2.COLOR_BGR2HSV)

    img_thresh_black = cv2.bitwise_or(
        cv2.inRange(img_hsv, LOWER_BLACK_THRESHOLD, UPPER_BLACK_THRESHOLD),
        cv2.inRange(img_hsv, LOWER_MAGENTA_THRESHOLD, UPPER_MAGENTA_THRESHOLD),
    )

    img_thresh_green = cv2.inRange(
        img_hsv, LOWER_GREEN_THRESHOLD, UPPER_GREEN_THRESHOLD
    )
    img_thresh_red = cv2.bitwise_or(
        cv2.inRange(img_hsv, LOWER_RED_THRESHOLD1, UPPER_RED_THRESHOLD1),
        cv2.inRange(img_hsv, LOWER_RED_THRESHOLD2, UPPER_RED_THRESHOLD2),
    )
    img_thresh_blue = cv2.inRange(img_hsv, LOWER_BLUE_THRESHOLD, UPPER_BLUE_THRESHOLD)
    img_thresh_orange = cv2.bitwise_or(
        cv2.inRange(img_hsv, LOWER_ORANGE_THRESHOLD1, UPPER_ORANGE_THRESHOLD1),
        cv2.inRange(img_hsv, LOWER_ORANGE_THRESHOLD2, UPPER_ORANGE_THRESHOLD2),
    )

    left_contours_bot, hierarchy = cv2.findContours(
        img_thresh_black[ROI_LEFT[1] : ROI_LEFT[3], ROI_LEFT[0] : ROI_LEFT[2]],
        cv2.RETR_EXTERNAL,
        cv2.CHAIN_APPROX_NONE,
    )
    right_contours_bot, hierarchy = cv2.findContours(
        img_thresh_black[ROI_RIGHT[1] : ROI_RIGHT[3], ROI_RIGHT[0] : ROI_RIGHT[2]],
        cv2.RETR_EXTERNAL,
        cv2.CHAIN_APPROX_NONE,
    )

    contours_red, _ = cv2.findContours(
        img_thresh_red[ROI_MIDDLE[1] : ROI_MIDDLE[3], ROI_MIDDLE[0] : ROI_MIDDLE[2]],
        cv2.RETR_EXTERNAL,
        cv2.CHAIN_APPROX_NONE,
    )
    contours_green, _ = cv2.findContours(
        img_thresh_green[ROI_MIDDLE[1] : ROI_MIDDLE[3], ROI_MIDDLE[0] : ROI_MIDDLE[2]],
        cv2.RETR_EXTERNAL,
        cv2.CHAIN_APPROX_NONE,
    )

    contours_blue, _ = cv2.findContours(
        img_thresh_blue[ROI_LINE[1] : ROI_LINE[3], ROI_LINE[0] : ROI_LINE[2]],
        cv2.RETR_EXTERNAL,
        cv2.CHAIN_APPROX_SIMPLE,
    )

    contours_orange, _ = cv2.findContours(
        img_thresh_orange[ROI_LINE[1] : ROI_LINE[3], ROI_LINE[0] : ROI_LINE[2]],
        cv2.RETR_EXTERNAL,
        cv2.CHAIN_APPROX_SIMPLE,
    )

    left_contours_black, hierarchy = cv2.findContours(
        img_thresh_black[ROI_LEFT[1] : ROI_LEFT[3], ROI_LEFT[0] : ROI_LEFT[2]],
        cv2.RETR_EXTERNAL,
        cv2.CHAIN_APPROX_NONE,
    )
    right_contours_black, hierarchy = cv2.findContours(
        img_thresh_black[ROI_RIGHT[1] : ROI_RIGHT[3], ROI_RIGHT[0] : ROI_RIGHT[2]],
        cv2.RETR_EXTERNAL,
        cv2.CHAIN_APPROX_NONE,
    )

    front_contours_black, hierarchy = cv2.findContours(
        img_thresh_black[ROI_FRONT[1] : ROI_FRONT[3], ROI_FRONT[0] : ROI_FRONT[2]],
        cv2.RETR_EXTERNAL,
        cv2.CHAIN_APPROX_NONE,
    )
    contours, hierarchy = cv2.findContours(
        img_thresh_black, cv2.RETR_EXTERNAL, cv2.CHAIN_APPROX_NONE
    )

    left_area = 0
    right_area = 0
    green_pillar_area = 0
    red_pillar_area = 0
    blue_line_area = 0
    orange_line_area = 0

    contours_coloured = [
        (contours_red, (0, 0, 255), 1, ROI_MIDDLE),
        (contours_green, (0, 255, 0), 1, ROI_MIDDLE),
        (contours, (0, 255, 255), 1, (0, 0)),
        (contours_orange, (52, 140, 235), 0, ROI_LINE),
        (contours_blue, (235, 67, 52), 0, ROI_LINE),
    ]

    left_area_black = findMaxContour(left_contours_black)
    right_area_black = findMaxContour(right_contours_black)
    front_area_black = findMaxContour(front_contours_black)
    left_area = left_area_black
    right_area = right_area_black

    for i in range(len(contours_orange)):
        cnt = contours_orange[i]
        orange_line_area = max(cv2.contourArea(cnt), orange_line_area)
        cnt[:, :, 0] += ROI_LINE[0]
        cnt[:, :, 1] += ROI_LINE[1]
        if SHOW_CONTOURS:

            cv2.drawContours(im, contours_orange, i, (255, 255, 0), 1)

    for i in range(len(contours_blue)):
        cnt = contours_blue[i]
        blue_line_area = max(cv2.contourArea(cnt), blue_line_area)
        cnt[:, :, 0] += ROI_LINE[0]
        cnt[:, :, 1] += ROI_LINE[1]
        if SHOW_CONTOURS:

            cv2.drawContours(im, contours_blue, i, (255, 255, 0), 1)

    for c in contours_coloured:
        cont = c[0]
        colour = c[1]
        ROIROI = c[3]
        for i, cnt in enumerate(cont):
            area = cv2.contourArea(cnt)
            if area > 100:
                cnt[:, :, 0] += ROIROI[0]
                cnt[:, :, 1] += ROIROI[1]
                if SHOW_CONTOURS:

                    cv2.drawContours(im, [cnt], -1, colour, 2)
    if startFromParkingLot:
        print("fajf " + str(right_area) + " " + str(left_area))

        if left_area < right_area:

            track_dir = "left"
            exit_parking_lot_left = True
            startFromParkingLot = False

        else:

            track_dir = "right"

            exit_parking_lot_right = True
            startFromParkingLot = False

    if exit_parking_lot_left:
        pw = pwm(0)

        board.pwm_servo_set_position(0.04, [[1, pw]])
        time.sleep(0.4)
        board.pwm_servo_set_position(0.04, [[2, DC_SPEED + 5]])

        time.sleep(0.8)

        exit_parking_lot_left = False

        board.pwm_servo_set_position(0.04, [[2, DC_SPEED]])

        turn_dir = None
        closest_pillar_distance = 10000
        closest_pillar_colour = None
        closest_pillar_area = -1

        print("aaaa" + str(closest_pillar_area) + " " + str(closest_pillar_distance))

    if exit_parking_lot_right:
        pw = pwm(MID_SERVO + MAX_TURN_DEGREE - 8)
        board.pwm_servo_set_position(0.04, [[1, pw]])

        board.pwm_servo_set_position(0.04, [[2, DC_SPEED + 9]])
        time.sleep(1.2)

        pw = pwm(MID_SERVO)
        board.pwm_servo_set_position(0.04, [[1, pw]])
        board.pwm_servo_set_position(0.04, [[2, DC_SPEED]])
        time.sleep(0.3)

        exit_parking_lot_right = False
        turn_dir = None

        closest_pillar_distance = 10000
        closest_pillar_colour = None
        closest_pillar_area = -1
        if not a:
            a = True

            continue

    num_pillars_r = 0
    num_pillars_g = 0

    OBSTACLEPG = 0.0013
    OBSTACLEPD = 0.0013
    YAXISPG = 0

    if turn_counter == 0 and track_dir == "left":
        OBSTACLEPG *= 2

    x, y, w, h = 0, 0, 0, 0

    closest_pillar_distance = 100000
    closest_pillar_x = None
    closest_pillar_y = None
    closest_pillar_area = None
    closest_pillar_colour = None

    for i in contours_red:
        area = cv2.contourArea(i)

        if area > PILLAR_SIZE:
            approx = cv2.approxPolyDP(i, 0.01 * cv2.arcLength(i, True), True)
            x, y, w, h = cv2.boundingRect(approx)

            pillar_distance = math.dist([x + w // 2, y], [320, 480])

            if pillar_distance < 500:
                if SHOW_CONTOURS:

                    image = cv2.line(im, (x, y), (x + w, y), (0, 255, 255), 1)
                    image = cv2.line(im, (x, y), ((x, h + y)), (0, 255, 255), 1)
                    image = cv2.line(im, (x + w, y), (x + w, y + h), (0, 255, 255), 1)
                    image = cv2.line(im, (x, y + h), (x + w, y + h), (0, 255, 255), 1)
                    cv2.circle(im, (int(x + (w / 2)), y), 5, (255, 255, 0), 1, -1)

                num_pillars_r += 1

                if pillar_distance < closest_pillar_distance:
                    if y + h > 450 and x + (w // 2) < red_target:
                        prevPillar = "red"
                        pass
                    elif y + h < 125:
                        print(y + h)
                        pass
                    else:
                        closest_pillar_distance = pillar_distance
                        closest_pillar_colour = "red"
                        closest_pillar_x = x + w // 2
                        closest_pillar_y = y
                        closest_pillar_area = h * w

    for i in contours_green:
        area = cv2.contourArea(i)

        if area > PILLAR_SIZE:
            approx = cv2.approxPolyDP(i, 0.01 * cv2.arcLength(i, True), True)
            x, y, w, h = cv2.boundingRect(approx)

            pillar_distance = math.dist([x + w // 2, y], [320, 480])

            if pillar_distance < 500:
                if SHOW_CONTOURS:
                    image = cv2.line(im, (x, y), (x + w, y), (0, 255, 255), 1)
                    image = cv2.line(im, (x, y), ((x, h + y)), (0, 255, 255), 1)
                    image = cv2.line(im, (x + w, y), (x + w, y + h), (0, 255, 255), 1)
                    image = cv2.line(im, (x, y + h), (x + w, y + h), (0, 255, 255), 1)
                    cv2.circle(im, (int(x + (w / 2)), y), 5, (255, 255, 0), 1, -1)

                num_pillars_g += 1

                if pillar_distance < closest_pillar_distance:
                    if y + h > 450 and (x + (w // 2) > green_target):
                        print("hello")
                        prevPillar = "green"
                        pass
                    elif y + h < 125:
                        print("hi")

                        pass
                    else:
                        closest_pillar_distance = pillar_distance
                        closest_pillar_colour = "green"
                        closest_pillar_x = x + w // 2
                        closest_pillar_y = y
                        closest_pillar_area = h * w

    if turn_counter >= MAX_TURNS and not parking_left or parking_right:
        if track_dir == "left" and not last_green_left_track:
            if closest_pillar_y != None:
                if target == green_target and closest_pillar_y < 300:
                    last_green_left_track = True
                else:
                    parking_left = True
            else:
                parking_left = True
        if track_dir == "right" and not last_red_right_track:
            print("a")
            if closest_pillar_y != None:
                if target == red_target and closest_pillar_y < 300:
                    last_red_right_track = True
                    print("c")

                else:
                    parking_right = True
            else:
                parking_right = True

    if last_green_left_track and not parking_left:
        if target == green_target:
            if closest_pillar_y is not None:
                if closest_pillar_y > 300:
                    # move forward
                    board.pwm_servo_set_position(0.04, [[1, pwm(MID_SERVO)]])
                    board.pwm_servo_set_position(0.1, [[2, DC_SPEED + 10]])
                    time.sleep(1)
                    """
                    not required
                    board.pwm_servo_set_position(0.1, [[2, 1500]])

                    time.sleep(3)
                    # stop for 3 seconds
                    """

                    # turn into right wall
                    board.pwm_servo_set_position(0.04, [[2, DC_SPEED + 5]])
                    servo_angle = MID_SERVO + MAX_TURN_DEGREE - 7
                    board.pwm_servo_set_position(0.04, [[1, pwm(servo_angle)]])
                    time.sleep(1.5)

                    servo_angle = MID_SERVO
                    board.pwm_servo_set_position(0.04, [[1, pwm(servo_angle)]])
                    time.sleep(0.8)

                    """
                    
                    
                    board.pwm_servo_set_position(0.1, [[2, 1620]])
                    board.pwm_servo_set_position(0.04, [[1, pwm(MID_SERVO)]])
                    time.sleep(1.5)
                    
                    """
                    # back up

                    board.pwm_servo_set_position(0.04, [[2, 1500]])

                    parking_left = True

    if last_red_right_track and not parking_right:
        print(closest_pillar_y)
        if closest_pillar_y > 250:
            board.pwm_servo_set_position(0.04, [[1, pwm(MID_SERVO)]])
            board.pwm_servo_set_position(0.1, [[2, DC_SPEED + 10]])
            time.sleep(1)
            parking_right = True

    if blue_line_area >= LINE_THRESHOLD and track_dir != "right" and seen_line == False:
        track_dir = "left"
        turn_dir = "left"
        seen_line = True
        turn_counter += 1
    if (
        orange_line_area >= LINE_THRESHOLD
        and track_dir != "left"
        and seen_line == False
    ):
        track_dir = "right"
        turn_dir = "right"
        seen_line = True
        turn_counter += 1

    if turn_dir == "left":
        if orange_line_area >= LINE_THRESHOLD:
            line_end = True

    if turn_dir == "right":
        if blue_line_area >= LINE_THRESHOLD:
            line_end = True

    if closest_pillar_colour == None:
        target = None
    elif closest_pillar_colour == "red":
        target = red_target
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

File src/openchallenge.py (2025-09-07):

# libraries
import cv2  # for image processing
import numpy as np  # for image manipulation
import time
import ros_robot_controller_sdk as rrc
import sys
import subprocess
import threading
import ros_robot_controller_sdk as rrc
from picamera2 import Picamera2
import RPi.GPIO as GPIO

board = rrc.Board()
# movement constants
MID_SERVO = 63
MAX_TURN_DEGREE = 28
DC_SPEED = 1374


# proportion constants for the servo motor angle (PID steering)
PD = 0.002
PG = 0.002
# no integral value


ROI_LEFT_BOT = [0, 245, 100, 480]
ROI_RIGHT_BOT = [540, 245, 640, 480]

ROI4 = [270, 380, 370, 400]


# color threshold constants (in HSV)
# LOWER_BLUE = np.array([104, 65, 70])
# UPPER_BLUE = np.array([132, 205, 185])
# LOWER_ORANGE1 = np.array([155, 59, 70])
# UPPER_ORANGE1 = np.array([180, 255, 255])
# LOWER_ORANGE2 = np.array([0, 59, 70])
# UPPER_ORANGE2 = np.array([8, 255, 255])

LOWER_ORANGE1 = np.array([180, 100, 100])
UPPER_ORANGE1 = np.array([180, 255, 255])
LOWER_ORANGE2 = np.array([5, 156, 120])
UPPER_ORANGE2 = np.array([20, 255, 255])

LOWER_BLUE = np.array([105, 45, 70])
UPPER_BLUE = np.array([130, 255, 200])


LOWER_BLACK_THRESHOLD = np.array([0, 0, 0])
UPPER_BLACK_THRESHOLD = np.array([180, 255, 65])


# camera settings
WIDTH = 640
HEIGHT = 480
POINTS = [(115, 200), (525, 200), (640, 370), (0, 370)]


# limiting constants
MAX_TURNS = 12
ACTIONS_TO_STRAIGHT = 90
WALL_THRESHOLD = 50
NO_WALL_THRESHOLD = 25
TURN_ITER_LIMIT = 30
LINE_THRESHOLD = 30


# incrementing variables
action_counter = 0
turn_counter = 0
turn_length_counter = 0
last_turn_count = 0

# dynamic variables
track_dir = None
done_turning = False
turn_dir = None
last_difference = 0
current_difference = 0
seen_line = False
line_end = False
button_pressed = False
# initialize servo angle variable
servo_angle = 0


# initialization of camera global variables
im = None
image = None


# camera setup
picam2 = Picamera2()
picam2.preview_configuration.main.size = (640, 480)
picam2.preview_configuration.main.format = "RGB888"
picam2.preview_configuration.controls.FrameRate = 30
picam2.configure("preview")
picam2.start()
time.sleep(15)


def listen_to_button_events():
    global button_pressed
    command = (
        "source /home/ubuntu/.zshrc && ros2 topic echo /ros_robot_controller/button"
    )
    process = subprocess.Popen(
        [
            "docker",
            "exec",
            "-u",
            "ubuntu",
            "-w",
            "/home/ubuntu",
            "MentorPi",
            "/bin/zsh",
            "-c",
            command,
        ],
        stdout=subprocess.PIPE,
        stderr=subprocess.PIPE,
        text=True,
    )

    while True:
        output = process.stdout.readline()
        if output:
            line = output.strip()
            if line.startswith("id:"):
                button_id = int(line.split(":")[1].strip())
            elif line.startswith("state:"):
                state = int(line.split(":")[1].strip())

                if button_id == 1:
                    if state == 1:
                        button_pressed = True
                        print("Button 1 pressed")
                elif button_id == 2:
                    if state == 1:
                        print("Button 2 pressed")
        else:
            continue


def check_node_status():
    command = "source /home/ubuntu/.zshrc && ros2 topic list"
    result = subprocess.run(
        [
            "docker",
            "exec",
            "-u",
            "ubuntu",
            "-w",
            "/home/ubuntu",
            "MentorPi",
            "/bin/zsh",
            "-c",
            command,
        ],
        capture_output=True,
        text=True,
    )
    res = result.stdout
    return "/ros_robot_controller/button" in res


# utility function for pwm angle calculation
def pwm(degree):  # angle must be adjusted to pwm angle for servo
    """
    Convert angle in degrees to pulse width modulation (PWM) for servo to understand

    Parameters:
    degree (int): The angle the servo should turn to.

    Returns:
    int: The equivalent pwm for the desired angle.
    """

    return round(degree * 11.1 + 500)


# utility function for drawing ROI
def drawROI(ROI):  # draw the rectangular ROI on the image
    """
    Displays/draws a rectanngular region of interest (ROI) on the OpenCV window

    Parameters:
    ROI (list): A list of 2 coodinates detailing the top left and the bottom right of the ROI

    Returns:

    """

    image = cv2.line(im, (ROI[0], ROI[1]), (ROI[2], ROI[1]), (0, 255, 255), 4)
    image = cv2.line(im, (ROI[0], ROI[1]), (ROI[0], ROI[3]), (0, 255, 255), 4)
    image = cv2.line(im, (ROI[2], ROI[3]), (ROI[2], ROI[1]), (0, 255, 255), 4)
    image = cv2.line(im, (ROI[2], ROI[3]), (ROI[0], ROI[3]), (0, 255, 255), 4)


# utility function for stopping the robot
def stop():
    """
    Sets servo and DC motor straight and closing the OpenCV window

    Parameters:

    Returns:

    """

    time.sleep(0.02)
    board.pwm_servo_set_position(0.1, [[2, 1500]])

    board.pwm_servo_set_position(0.1, [[1, pwm(MID_SERVO)]])

    cv2.destroyAllWindows()


if check_node_status():
    print("ROS2 node detected")
    listener_thread = threading.Thread(target=listen_to_button_events, daemon=True)
    listener_thread.start()


# setting servo angle to straight and the motor to stationary
board.pwm_servo_set_position(0.1, [[1, pwm(MID_SERVO)]])
# turn servo to mid
board.pwm_servo_set_position(0.1, [[2, 1500]])  # arm the esc motor
time.sleep(0.5)
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

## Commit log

2025-02-09 bldc controller code
2025-05-04 added Gyroscope based loop
2025-05-11 fix steering
2025-05-11 Created loop driver
    turns slight off
2025-06-01 open challenge mid servo change
2025-06-27 changed parking algorithm in specific green pillar case
2025-06-28 Create . …
2025-07-06 Rough Assembly Additions
2025-07-06 Rename camera holder 2 Drawing_pages-to-jpg-0001.jpg to camera holder 2 Drawing.jpg
2025-07-07 Rename camera holder 2 Drawing.pdf to camera-holder-drawing.pdf
2025-07-07 Rename camera holder 2 Drawing.jpg to camera-holder-drawing.jpg
2025-07-27 Rename Raspberry Pi 5.png to Raspberry-Pi-5.png
2025-07-27 Rename HS-5055MG Servo.jpg to HS-5055MG-Servo.jpg
2025-07-27 Rename Furitek Micro Komodo Motor.jpg to Furitek-Micro-Komodo-Motor.jpg
2025-08-12 created engineering materials and assembly
2025-08-24 added obstacle challenge parking and changed obstacle avoidance
    [obstaclechallenge.py]
2025-08-24 Lidar parser and plotter codes added
2025-08-24 Added program that follows a wall to the right using lidar
2025-08-24 added stl files organization needed
    [Camera_Mount_V2.stl, Part Studio 1 - Part 1.stl, Part Studio 1.stl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]
2025-08-24 Update README.md
    raspberry pi text formatting
2025-08-28 reorganized models
    [holder (1).stl, holder.stl, holder2.stl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]
2025-08-28 reorganizing models
    [Camera_Mount_V2.stl, Part Studio 1 - Part 1.stl, Part Studio 1.stl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]
2025-08-28 Rename Gens Ace 2S1P 1300mAh 7.4V battery.jpg to Gens-Ace-2S1P-1300mAh-7.4V-battery.jpg
2025-08-28 reorganize models
    [Camera_Mount_V2.stl, Part Studio 1.stl, baseplate1.stl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]
2025-08-28 finalized models
    [baseplate3.stl, cameraholder3.stl, front3.stl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]
2025-08-28 motor image
2025-08-28 change parking and wall avoidance
    [obstaclechallenge.py]
2025-09-04 added exterior pillar override case
2025-09-07 added wiring diagram
2025-09-07 changes to open challenge turn and added auto start and button press to start
2025-09-07 imu program
2025-09-07 added esc image
2025-09-07 added esc to motor selection
2025-09-07 motor mount changed documentation
2025-09-08 assembly changes
2025-09-08 update flowchart
2025-09-08 software assembly
2025-09-08 fixed wiring diagrams
2025-09-08 wiring schematic changes
2025-09-08 schematic changes
